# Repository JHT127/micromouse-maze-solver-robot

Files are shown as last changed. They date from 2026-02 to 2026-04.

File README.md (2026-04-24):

# 🐭 Micromouse Maze Solver Robot

> An autonomous maze-solving robot built from scratch — custom 3D-printed chassis, embedded C++ firmware, and classical control theory running on an ESP32.

**Team**:  Joud Thaher · Layan Salem · Labiba Sharia · Waad Ziadeh

**Instructor**: Dr. Wasel  

**University**: Birzeit University 

**Robot Name**: SHAMSHOON

---

## 🎯 What This Project Does

The robot navigates an 8×8 cell maze autonomously without any human input. It:

1. **Senses** walls in real time using three LIDAR sensors (front, left, right)
2. **Localises** itself in the maze using wheel encoders + gyroscope (StateSpace model)
3. **Plans** the shortest path to the center using the Flood Fill algorithm (BFS)
4. **Executes** precise movements using dual PID controllers — one per wheel
5. **Updates** its wall map as it explores and re-solves the path dynamically

Everything — from the PCB wiring to the 3D-printed body to the firmware — was designed and built by the team.

---

## 📸 Demo & Documentation

| Resource | Link |
|---|---|
| 📄 Full Project Presentation | [`docs/presentation.pdf`](docs/presentation.pdf) |
| 🗂️ Project Journey (Trello) | [Trello Board](https://trello.com/b/NDhEVEoG/micromouse-maze-solver-project) |
| 🏗️ Software Architecture | [`docs/ARCHITECTURE.md`](docs/ARCHITECTURE.md) |
| 🔧 Hardware Overview | [`hardware/README.md`](hardware/README.md) |
| 🖨️ 3D Print Files | [`hardware/3d-models/`](hardware/3d-models/) |

---

## 🤖 System Overview

```
┌─────────────────────────────────────────────────────────┐
│                    MazeNavigator                        │  ← Orchestration
├──────────────────────┬──────────────────────────────────┤
│     FloodFill        │       MotionController           │  ← Planning & Control
│  (BFS path solver)   │  (PID + StateSpace + gyro)      │
├──────────────────────┴──────────────────────────────────┤
│  LIDARSensor ×3  │  Encoder ×2  │  MPU6050Driver       │  ← Sensing
├──────────────────┴──────────────┴──────────────────────-┤
│              Motor ×2  │  PIDController ×2              │  ← Actuation
└─────────────────────────────────────────────────────────┘
                       ESP32 (Dual-core)
```

---

## 🛠️ Hardware Stack

| Component | Part | Role |
|---|---|---|
| **MCU** | ESP32 Dev Kit + Shield | Brain — dual-core processing, all GPIO |
| **Motors** | 2× N20 DC + L298N H-bridge | Differential drive |
| **Encoders** | 530 PPR wheel encoders | Odometry / speed feedback |
| **LIDAR** | 3× VL53L0X (I2C) | Wall detection: front, left, right |
| **IMU** | MPU6050 (6-axis) | Gyroscope for heading, accel for tilt |
| **Power** | Li-ion battery + Buck-Boost | Stable voltage across charge levels |
| **Chassis** | Custom 3D-printed PLA | Compact, lightweight, maze-optimised |

---

## 💻 Software Stack

| Layer | Module | What it does |
|---|---|---|
| **Sensing** | `LIDARSensor`, `MPU6050Driver`, `Encoder` | Read raw hardware data |
| **Control** | `PIDController`, `Motor` | Regulate wheel speed via PWM |
| **Localisation** | `StateSpace` | Kinematic model → tracks (x, y, θ) |
| **Motion** | `MotionController` | High-level: move forward, turn 90° |
| **Planning** | `FloodFill` | BFS flood → distance field for 8×8 maze |
| **Integration** | `MazeNavigator` | Ties everything into a solve loop |

**Toolchain**: C++ · Arduino Framework · PlatformIO · VS Code  
**Libraries**: `Adafruit MPU6050`, `Pololu VL53L0X`

---

## 🚀 Quick Start (Software)

### Prerequisites
- [VS Code](https://code.visualstudio.com/) + [PlatformIO extension](https://platformio.org/install/ide?install=vscode)
- ESP32 connected via USB

### Steps

```bash
git clone https://github.com/JHT127/micromouse-maze-solver-robot.git
cd micromouse-maze-solver-robot/software
```

Open in VS Code → PlatformIO will auto-install dependencies.

Edit `software/platformio.ini` to set your port:
```ini
upload_port = COM4       # Windows — change to your port
# upload_port = /dev/ttyUSB0   # Linux
# upload_port = /dev/cu.SLAB_USBtoUART  # macOS
```

```bash
# Build & upload firmware
platformio run -t upload

# Monitor serial output
platformio device monitor --baud 9600
```

> ⚠️ Keep the robot stationary during startup — the IMU calibrates for 500 samples.

---

## 📂 Repository Structure

```
micromouse-maze-solver-robot/
│
├── README.md                   ← You are here
│
├── docs/
│   ├── presentation.pdf        ← Full project presentation
│   ├── ARCHITECTURE.md         ← Deep-dive: algorithms & design decisions
│   └── component-READMEs/     ← Per-module documentation
│       ├── FloodFill.md
│       ├── PIDController.md
│       ├── StateSpace.md
│       └── ...
│
├── hardware/
│   ├── README.md               ← Hardware setup, wiring, BOM
│   └── 3d-models/             ← STL files for chassis 
│   
│
└── software/                   ← All firmware (PlatformIO project)
    ├── platformio.ini
    ├── src/
    │   └── main.cpp            ← Entry point
    ├── lib/                    ← 9 modular libraries
    │   ├── Motor/
    │   ├── Encoder/
    │   ├── PIDController/
    │   ├── StateSpace/
    │   ├── MPU6050Driver/
    │   ├── MotionController/
    │   ├── LIDARSensor/
    │   ├── FloodFill/
    │   └── MazeNavigator/
    ├── include/
    │   └── pins.h              ← All GPIO pin definitions
    ├── test/                   ← 12 unit + integration tests
    └── _archive_legacy_tests/  ← Early exploratory tests (historical)
```

---

## 🧪 Tests

12 tests cover every major component:

| Test | Type | What's validated |
|---|---|---|
| `FloodFill_test` | Unit | BFS algorithm, distance field, wall encoding |
| `PIDController_test` | Unit | Gain tuning, step response |
| `StateSpace_test` | Unit | Position prediction, coordinate transforms |
| `Encoders_Motors_test` | Unit | Speed measurement, PWM output |
| `LIDARSensor_test` | Unit | I2C addresses, ranging |
| `MPU6050_test` | Unit | Init, calibration, gyro drift |
| `MotionController_test` | Integration | Forward + turn commands |
| `turn_90_test` | Integration | Rotation accuracy |
| `MoveForward_WallDetection_test` | Integration | Movement + obstacle avoidance |
| `moveAndTurn_Test` | Integration | Sequential motion patterns |
| `CollisionAvoidance_test` | Integration | Emergency stop |
| `MazeNavigator_test` | Integration | Full maze solve loop |

See [`software/test/README.md`](software/test/README.md) for how to run individual tests.

---

## 🖨️ 3D Printing

The robot chassis was designed in-house and 3D-printed in PLA. Key design decisions:
- **Compact footprint** — fits within maze cell constraints
- **Lightweight** — reduces motor load, improves acceleration
- **Cardboard prototype first** — we validated dimensions before printing

STL files are in [`hardware/3d-models/`](hardware/3d-models/).  
*(If you're replicating this project, we recommend printing at 20% infill with 0.2mm layer height.)*

---

## 📐 Key Algorithms

### Flood Fill (Path Planning)
BFS from the goal (center 4 cells of the 8×8 grid) outward. Each cell stores a distance value and 4-bit wall encoding. The robot always moves to the lowest-distance neighbour — guaranteed shortest path.

### PID Control (Speed Regulation)
One PID per wheel. Input: target velocity. Feedback: encoder ticks. Output: PWM (0–255). Update rate: 50 Hz. Gains tuned manually: start with P, add I to remove steady-state error, add D to reduce oscillation.

### State Space (Localisation)
Kinematic differential-drive model tracking `[x, y, θ]`. Linear velocity from encoders, angular velocity from gyroscope. Heading convention: 0° = North, 90° = East, clockwise positive.

---

## 🔐 Security Note

This repository contains **no credentials, API keys, or Wi-Fi passwords**. The `platformio.ini` file contains a COM port reference (`COM4`) — update this to match your machine before uploading. No other machine-specific configuration is hardcoded.

---

## 📄 License

This project is submitted as academic coursework. You are welcome to study, fork, and learn from the code. Please note that we are students and still learning, so double-check everything. Do not forget to check out our journey documented on trello (the link is provided above if you click on the words Trello Board)!

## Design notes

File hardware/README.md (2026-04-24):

# 🔧 Hardware

This directory covers the physical robot — components, wiring, power, and mechanical design.

---

## Bill of Materials (BOM)

| # | Component | Qty | Purpose |
|---|---|-----|---|
| 1 | ESP32 Dev Kit (30-pin) + Shield | 1 | Main microcontroller — dual-core, 34 GPIO |
| 2 | L298N H-bridge Motor Driver | 1 | Drives both DC motors (handles high current) |
| 3 | N20 DC Motor (geared) | 2 | Differential drive locomotion |
| 4 | Wheel Encoder (530 PPR) | 2 | Odometry — measures exact wheel rotation |
| 5 | VL53L0X LIDAR (ToF sensor) | 3 | Wall detection: front, left, right |
| 6 | MPU-6050 IMU | 1 | 3-axis gyroscope + 3-axis accelerometer |
| 7 | Driven wheels | 2 | Forward/backward/turning motion |
| 8 | Caster wheel | 1 | Balance without extra motor |
| 9 | Lithium-ion battery | 1 | Main power source |
| 10 | Buck-Boost converter | 1 | Regulates voltage as battery drains |
| 11 | 3D-printed PLA chassis | 1 | Custom compact body |

---

## Wiring Summary

```
ESP32 GPIO          → Peripheral
─────────────────────────────────
GPIO 21 (SDA)       → All I2C devices (VL53L0X ×3, MPU6050)
GPIO 22 (SCL)       → All I2C devices
GPIO MOTOR_LEFT_A/B → L298N IN1/IN2
GPIO MOTOR_RIGHT_A/B→ L298N IN3/IN4
GPIO MOTOR_LEFT_PWM → L298N ENA (PWM)
GPIO MOTOR_RIGHT_PWM→ L298N ENB (PWM)
GPIO ENCODER_LEFT_A/B  → Left encoder A/B channels
GPIO ENCODER_RIGHT_A/B → Right encoder A/B channels
GPIO LIDAR_*_XSHOT  → VL53L0X XSHUT pins (for I2C address assignment)
GPIO LIDAR_*_INT    → VL53L0X interrupt pins
```

Full pin mapping: [`../software/include/pins.h`](../software/include/pins.h)

---

## I2C Address Assignment

The three VL53L0X sensors share the I2C bus but are assigned unique addresses at startup:

| Sensor | Address | XSHUT pin |
|---|---|---|
| Front LIDAR | `0x30` | `LIDAR_FRONT_XSHOT` |
| Left LIDAR | `0x31` | `LIDAR_LEFT_XSHOT` |
| Right LIDAR | `0x32` | `LIDAR_RIGHT_XSHOT` |

Sensors are enabled one at a time during boot — see `setup()` in `src/main.cpp`.

---

## Power Architecture

```
Li-ion Battery
      │
  Buck-Boost Converter (regulates output voltage)
      │
      ├──→ L298N (motor power, 7–12V line)
      └──→ ESP32 + Sensors (3.3V / 5V logic)
```

The buck-boost converter maintains stable voltage even as the battery discharges — critical for consistent PID and sensor performance.

---

## 3D Printed Chassis

See [`3d-models/`](3d-models/) for STL files.

**Design rationale:**
- Compact footprint to fit maze cells cleanly
- Lightweight PLA body reduces motor load → better acceleration
- Cardboard prototype was built first to validate dimensions before printing
- Component placement tested on cardboard before committing to print

**Recommended print settings:**
- Material: PLA
- Layer height: 0.2 mm
- Infill: 20%
- Supports: as needed for overhangs

---

## Component Notes

### ESP32 + Shield
The shield provides organized breakout connections and stable power rails. The dual-core processor lets us handle sensor reads and motor control simultaneously without blocking.

### L298N H-bridge
GPIO pins cannot supply enough current to drive motors directly. The L298N acts as a power bridge: it takes low-current direction signals from ESP32 GPIO and PWM signals for speed, and delivers the high-current output the motors need.

### VL53L0X LIDAR (×3)
Uses time-of-flight laser pulses — more reliable than ultrasonic in speed and precision. Three sensors give the robot full left/front/right wall awareness. Range: 50–1200 mm.

### MPU-6050
6-axis IMU. We use the gyroscope to confirm accurate 90° turns and correct wheel-slippage errors that encoders alone would miss. Works in combination with encoders for more reliable heading estimation.

### N20 Motors + Encoders
530 PPR encoders on motor shafts provide tick-level feedback. Used to calculate: exact distance travelled per tick, real-time wheel velocity (fed into PID), and odometry for the StateSpace position model.

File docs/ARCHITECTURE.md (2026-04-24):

# Architecture & Development Guide

This document explains the software architecture, design patterns, and how to extend the codebase.

## 🏗️ Architecture Overview

The micromouse software is organized into **9 independent layers**, each with clear responsibilities:

```
┌─────────────────────────────────────────┐
│  LAYER 9: MAZE NAVIGATOR                │  Application logic
│  Orchestrates all systems for maze-solving
└────────────────┬────────────────────────┘
                 │
┌─────────────────┴────────────────────────┐
│  LAYER 8: FLOOD FILL ALGORITHM            │  Path planning
│  BFS-based pathfinding on 8×8 grid        │
└─────────────────────────────────────────┘
                 │
┌─────────────────┴────────────────────────────────┐
│  LAYER 7: MOTION CONTROLLER                      │  Motion commands
│  High-level primitives: moveForward(), turnRight()
└────────────────┬────────────────┬────────────────┘
                 │                │
     ┌───────────┴────────────────┴────────────┐
     │                                         │
┌────┴──────────────────────┐   ┌─────────────┴──────────────┐
│ LAYER 6: CONTROL SYSTEMS   │   │ LAYER 6: PERCEPTION        │
│ ├─ PID Controllers        │   │ ├─ LIDAR Sensors (3x)      │
│ ├─ StateSpace Tracker     │   │ ├─ MPU6050 IMU             │
│ └─ Feedback Loops         │   │ └─ Sensor Fusion            │
└────┬──────────────────────┘   └─────────────┬──────────────┘
     │                                        │
     │  ┌────────────────────────────────────┘
     │  │
┌────┴──┴─────────────────────────────────────┐
│  LAYER 5: HARDWARE ABSTRACTION               │
│  ├─ Motor (PWM + direction)                 │
│  ├─ Encoder (GPIO + interrupt)              │
│  ├─ I2C Drivers (IMU, LIDAR)                │
│  └─ GPIO Pin Management                     │
└─────────────┬────────────────────────────────┘
              │
┌─────────────┴────────────────────────────────┐
│  LAYER 4: HARDWARE (Physical devices)        │
│  ├─ ESP32 Microcontroller                   │
│  ├─ L298N H-Bridge (motors)                 │
│  ├─ N20 DC Motors + Encoders                │
│  ├─ VL53L0X LIDAR (3x)                      │
│  └─ MPU6050 IMU                              │
└──────────────────────────────────────────────┘
```

## 🔧 Design Patterns Used

### 1. **Layered Architecture**
- Each layer depends only on layers below it
- Lower layers are generic and reusable
- Upper layers are robot-specific

**Example**: `MotionController` (Layer 7) uses `Motor` (Layer 5) but `Motor` knows nothing about motion.

### 2. **Hardware Abstraction**
- Hardware classes encapsulate device communication
- Application code never directly accesses GPIO/I2C
- Easy to swap implementations

**Example**: To use different motors, only modify `lib/Motor/Motor.cpp`, not application code.

### 3. **Composition Over Inheritance**
- `MazeNavigator` contains instances of other classes
- No deep inheritance hierarchies
- Easier to understand and modify

**Example**: `MazeNavigator` has a `MotionController*` pointer, not inheriting from it.

### 4. **Single Responsibility Principle**
- Each class does one thing well
- `Motor` only drives motors, doesn't track position
- `Encoder` only counts ticks, doesn't control motion

## 📚 Library Details

### Layer 5: Hardware Abstraction

#### `Motor.h` / `Motor.cpp`
```cpp
class Motor {
private:
    int pinA, pinB, pinPWM;  // H-bridge pins
public:
    void forward(int pwm);    // 0-255
    void backward(int pwm);   // 0-255
    void stop();
    void brake();
};
```
**Key Points**:
- Abstracts L298N H-bridge complexity
- PWM range: 0-255 (0% to 100%)
- No state tracking (stateless)

#### `Encoder.h` / `Encoder.cpp`
```cpp
class Encoder {
private:
    long tickCount;           // Interrupt-updated
    static Encoder* leftEncoderPtr;  // ISR access
public:
    long getTicks();
    float getDistance();      // In meters
    float getVelocity(float deltaTime);
};
```
**Key Points**:
- Uses hardware interrupts for accuracy
- No polling → always current
- Interrupt-driven (ISR called per encoder tick)

#### `LIDARSensor.h` / `LIDARSensor.cpp`
```cpp
class LIDARSensor {
private:
    int I2C_address;          // 0x30, 0x31, 0x32
public:
    void enable();            // Power on via GPIO
    void initialize(int address);
    uint16_t getRange();      // In mm
    void startContinuous();   // Continuous polling mode
};
```
**Key Points**:
- Multiple sensors, each with unique I2C address
- XSHUT pin for address control
- Range: 50-1200mm (0.05-1.2m)

#### `MPU6050Driver.h` / `MPU6050Driver.cpp`
```cpp
class MPU6050Driver {
private:
    float heading;
    float gyroBias;           // Calibration offset
public:
    bool initialize();        // Returns false if not found
    void calibrate(int samples);  // Zero gyro bias
    float getHeading();       // In degrees (0-360)
    void update();            // Call frequently
};
```
**Key Points**:
- Integrates gyro readings to heading angle
- Must calibrate (keep still 5 sec)
- Output: absolute heading (0=North, 90=East, etc.)

### Layer 6: Control Systems

#### `PIDController.h` / `PIDController.cpp`
```cpp
class PIDController {
private:
    float Kp, Ki, Kd;         // Tuning coefficients
    float integral, lastError;
public:
    PIDController(float kp, float ki, float kd);
    float calculate(float error, float deltaTime);
    void setOutputLimits(float min, float max);
};
```
**Key Points**:
- Generic PID for any process
- Output clamped to [-255, 255] for motor PWM
- For velocity: `error = targetVelocity - actualVelocity`

#### `StateSpace.h` / `StateSpace.cpp`
```cpp
class StateSpace {
private:
    float x, y, theta;        // Robot position
public:
    void update(float linVel, float angVel, float dt);
    float getX();
    float getY();
    float getTheta();         // In radians
};
```
**Key Points**:
- Integrates velocity into position
- Used to track robot location on maze grid
- Theta in radians (0 = East, π/2 = North, π = West, 3π/2 = South)

### Layer 7: Motion Control

#### `MotionController.h` / `MotionController.cpp`
```cpp
class MotionController {
private:
    Motor* leftMotor, *rightMotor;
    Encoder* leftEncoder, *rightEncoder;
    PIDController* leftPID, *rightPID;
    StateSpace* robot;
    // ... state for current motion ...
public:
    void moveForward(float distance);  // Non-blocking
    void turnRight(float angle);       // Non-blocking
    bool isMoving();                   // Check if done
    void update();                     // Call every 20ms
};
```
**Key Points**:
- Non-blocking: returns immediately
- Call `update()` in main loop to drive motion
- Coordinates PID + encoders + IMU

### Layer 8: Path Planning

#### `FloodFill.h` / `FloodFill.cpp`
```cpp
class FloodFill {
private:
    uint8_t walls[8][8];      // Bitfield: N=1, E=2, S=4, W=8
    uint16_t distances[8][8]; // BFS distance from goal
public:
    void updateWalls(Cell cell, bool front, bool right, bool left, Direction heading);
    Direction getNextMove(Cell current, Direction heading);
};
```
**Key Points**:
- Maze grid: 8×8 cells (Japanese Micromouse standard)
- BFS calculates shortest path from current position to goal
- Wall encoding: bitwise (each direction is one bit)

### Layer 9: System Integration

#### `MazeNavigator.h` / `MazeNavigator.cpp`
```cpp
class MazeNavigator {
private:
    MotionController* motion;
    LIDARSensor* frontLidar, *leftLidar, *rightLidar;
    FloodFill* maze;
public:
    void initialize(Cell start, Direction heading);
    void step();              // Call every 20ms in main loop
    bool isComplete();        // True when maze solved
};
```
**Key Points**:
- Orchestrates all subsystems
- Main loop: Sense → Plan → Act
- Two modes: exploration (learning map) and speed run (known map)

## 🔄 Data Flow Example: Moving Forward

```
main.cpp:setup()
  └─> navigator.initialize(Cell(0,0), NORTH)
  
main.cpp:loop() [every 20ms]
  └─> navigator.step()
       ├─> frontLidar.getRange()           [Sense]
       ├─> leftLidar.getRange()
       ├─> rightLidar.getRange()
       │
       ├─> floodFill.updateWalls(...)      [Plan]
       ├─> direction = floodFill.getNextMove(...)
       │
       ├─> motion.moveForward(distance)    [Act]
       │   ├─> leftMotor.forward(pwm)
       │   ├─> rightMotor.forward(pwm)
       │   └─> motion.update()
       │       ├─> leftEncoder.getVelocity()
       │       ├─> rightEncoder.getVelocity()
       │       ├─> leftPID.calculate(error)
       │       ├─> rightPID.calculate(error)
       │       ├─> imu.getHeading()
       │       └─> robot.update(velocity, heading)
       │
       └─> [Repeat next iteration]
```

## 🔨 How to Add a New Component

### Example: Adding a Compass Sensor

**Step 1: Create Hardware Abstraction** (`lib/CompassSensor/`)
```cpp
// CompassSensor.h
class CompassSensor {
private:
    int I2C_address;  // HMC5883L default: 0x1E
public:
    bool initialize();
    float getHeading();  // Returns 0-360 degrees
};

// CompassSensor.cpp
bool CompassSensor::initialize() {
    Wire.beginTransmission(I2C_address);
    // ... initialization code ...
}

float CompassSensor::getHeading() {
    // Read X, Y from sensor, calculate heading
}
```

**Step 2: Add to Higher Layers**
Update `StateSpace.cpp`:
```cpp
class StateSpace {
private:
    CompassSensor compass;  // Add this
public:
    void update(float linVel, CompassSensor& compass) {  // Add parameter
        // Use compass.getHeading() instead of gyro estimate
    }
};
```

**Step 3: Create Unit Test** (`test/CompassSensor_test.cpp`)
```cpp
#include "CompassSensor.h"

CompassSensor compass;

void setup() {
    Serial.begin(9600);
    compass.initialize();
}

void loop() {
    float heading = compass.getHeading();
    Serial.println(heading);
    delay(100);
}
```

**Step 4: Document** (add to `READMEs/CompassSensor.md`)

**Step 5: Update READMEs**
- Update `README.md` with new layer or component
- Update `test/README.md` with new test
- Update this file with new architecture

## 🎯 Code Style Guidelines

### Commenting Convention
All code uses this header format:
```cpp
//------------------------------------------------------------
// SECTION HEADER
// Purpose: Explanation of why this exists
//------------------------------------------------------------
```

### Variable Naming
- Member variables: camelCase (`motorSpeed`, `encoderCount`)
- Constants: UPPER_CASE (`MOTORS_PER_TICK`, `MAZE_SIZE`)
- Functions: camelCase (`initialize()`, `getDistance()`)

### Class Organization
```cpp
class MyClass {
private:
    // Declare member variables
    // Define helper functions
    
public:
    // Declare public interface
    // Getters first
    // Setters second
    // Action methods third
};
```

### Comments
- **Why** comments above complex code
- **What** comments only if code is unclear
- Avoid obvious comments
```cpp
// Good
if (range < WALL_DISTANCE) {
    // Stop immediately - collision imminent
    motor.stop();
}

// Bad
int x = 5; // Set x to 5
```

## 🧪 Testing Strategy

### Unit Test Pattern
```cpp
// Test only ONE component
// Setup: Create instance, initialize
// Execute: Call methods
// Verify: Check Serial output
// Halt: while(1) delay(1000);
```

### Integration Test Pattern
```cpp
// Test MULTIPLE components working together
// Setup: Initialize all components
// Execute: Run realistic scenario
// Verify: Check combined behavior
// Halt: when complete
```

## 🚀 Performance Considerations

### Critical Timing
- **Main loop**: Must run at 50Hz (20ms)
- **Encoder ISR**: Must complete <100µs
- **Motor PWM**: 20kHz (ESP32 default)

### Memory Usage
- **Stack**: ~4KB used (ESP32 has 2KB SRAM per stack)
- **Heap**: ~50KB available for objects
- **Flash**: ~500KB used for code

## 🔍 Debugging Tips

### Use Serial Monitor
```cpp
Serial.print("Motor PWM: ");
Serial.println(pwmValue);
delay(100);  // Don't flood Serial!
```

### Common Issues
1. **Motors not responding**: Check motor power supply, GPIO pins
2. **Encoder counts wrong**: Verify PPR constant, check GPIO interrupts
3. **LIDAR I2C failing**: Check pull-up resistors, address selection
4. **IMU calibration fails**: Ensure board is level and motionless

## 📚 Further Reading

- `READMEs/` directory - Component-specific details
- `test/` directory - Working code examples
- `src/main.cpp` - Real application code
- Individual `.h` files - API documentation

---

**Last Updated**: April 24, 2026
**Status**: Complete Architecture Documentation

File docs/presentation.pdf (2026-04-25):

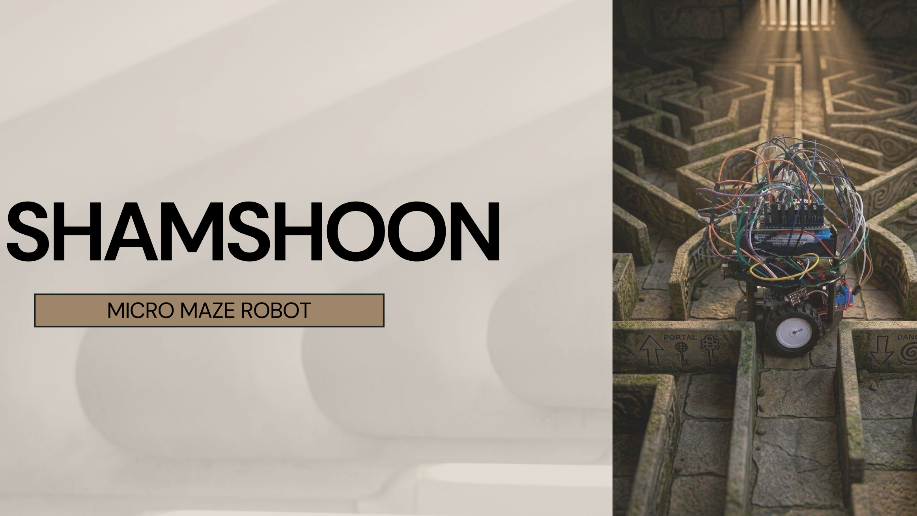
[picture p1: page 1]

# SHAMSHOON

MICRO MAZE ROBOT

# Our team

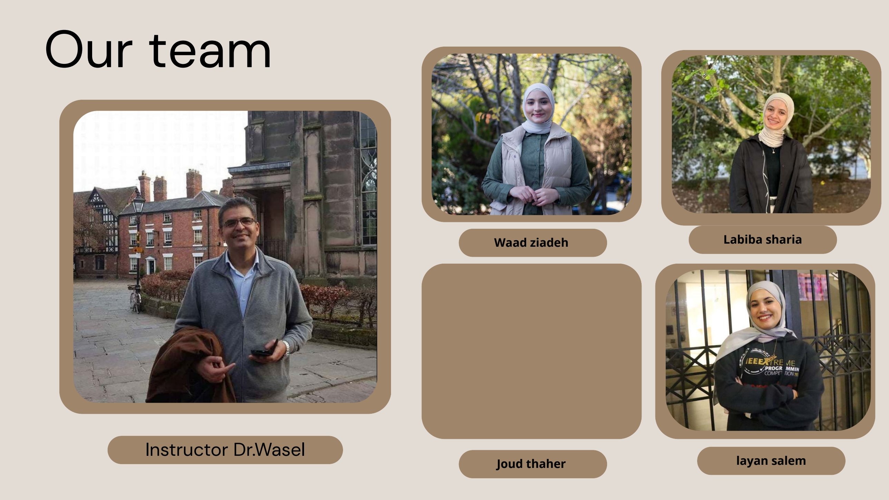
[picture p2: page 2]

Instructor Dr.Wasel

Waad ziadeh | Labiba sharia

Joud thaher

layan salem

# Component Overview & Purpose

### 7 Components

3

### 2 Motors

Sensors

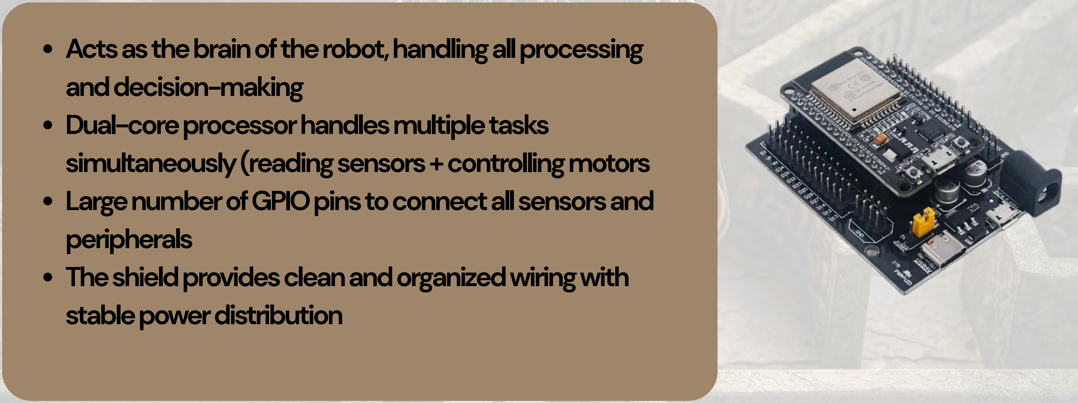
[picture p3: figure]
and decision-making Dual-core processor handles multiple tasks; peripherals; stable power distribution

Acts as the brain of the robot, handling all processing

simultaneously (reading sensors + controlling motors Large number of GPIO pins to connect all sensors and

The shield provides clean and organized wiring with

### 1 ESP32 + Shield Microcontroller

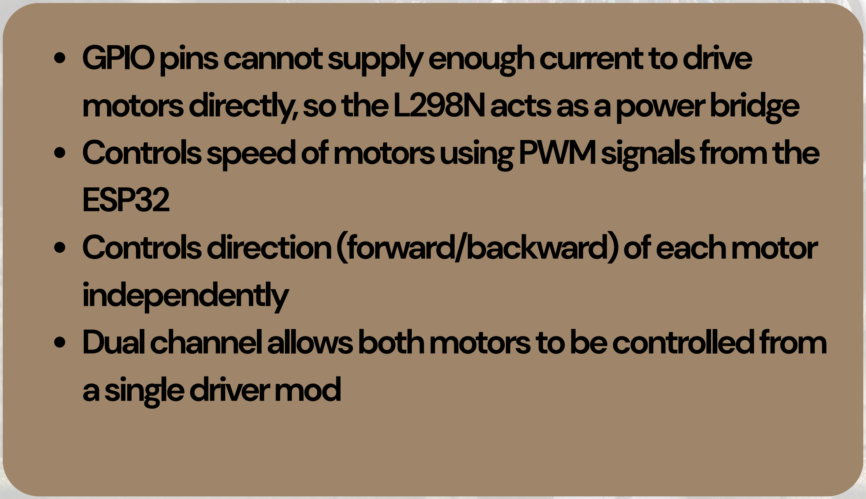
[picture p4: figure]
ESP32; independently; a single driver mod

GPIO pins cannot supply enough current to drive motors directly, so the L298N acts as a power bridge Controls speed of motors using PWM signals from the

Controls direction (forward/backward) of each motor

Dual channel allows both motors to be controlled from

### 2 L298N Motor Driver (H bridge)

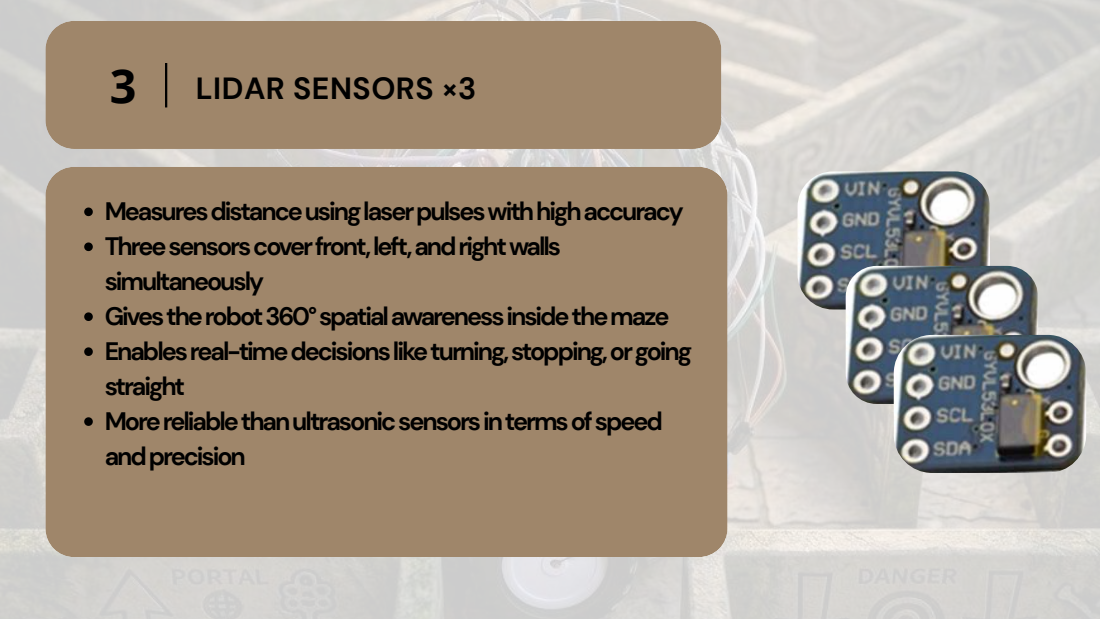
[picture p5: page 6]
3 LIDAR SENSORS ×3

Measures distance using laser pulses with high accuracy
Three sensors cover front, left, and right walls
simultaneously
Gives the robot 360° spatial awareness inside the maze
Enables real-time decisions like turning, stopping, or going
straight
More reliable than ultrasonic sensors in terms of speed
and precision

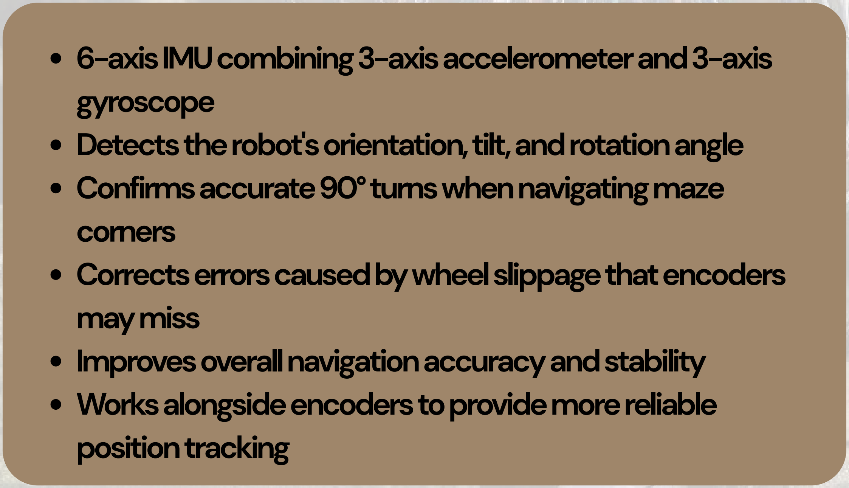
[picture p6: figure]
gyroscope; corners; may miss; position tracking
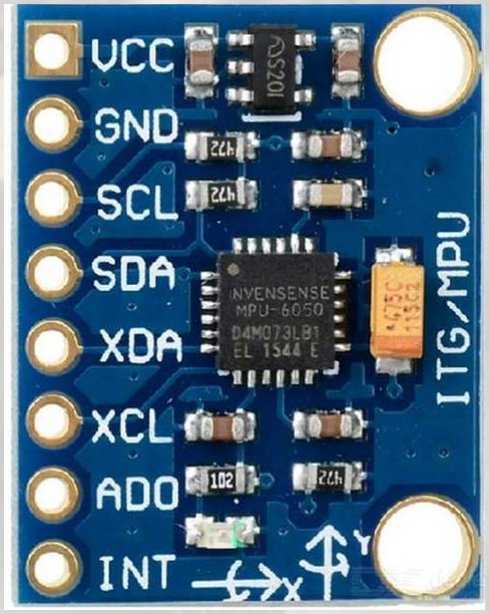
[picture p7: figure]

6-axis IMU combining 3-axis accelerometer and 3-axis

Detects the robot's orientation, tilt, and rotation angle Confirms accurate 90° turns when navigating maze

Corrects errors caused by wheel slippage that encoders

Improves overall navigation accuracy and stability Works alongside encoders to provide more reliable

### 4 MPU-6050 (Accelerometer + Gyroscope)

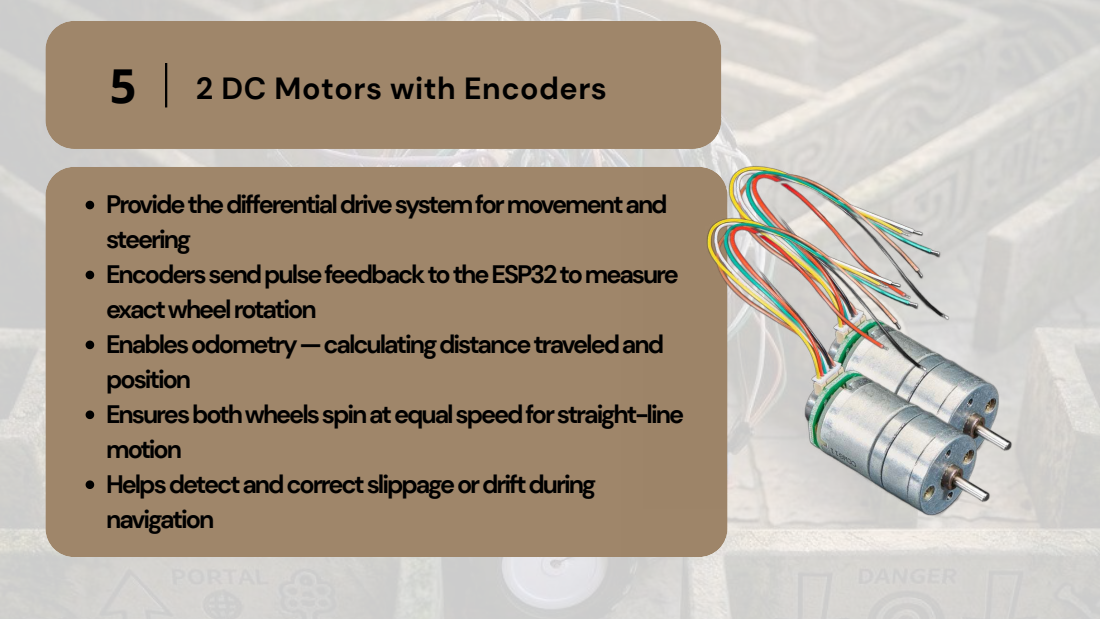
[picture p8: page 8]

5 2 DC Motors with Encoders

Provide the differential drive system for movement and
steering
Encoders send pulse feedback to the ESP32 to measure
exact wheel rotation
Enables odometry — calculating distance traveled and
position
Ensures both wheels spin at equal speed for straight-line
motion
Helps detect and correct slippage or drift during
navigation

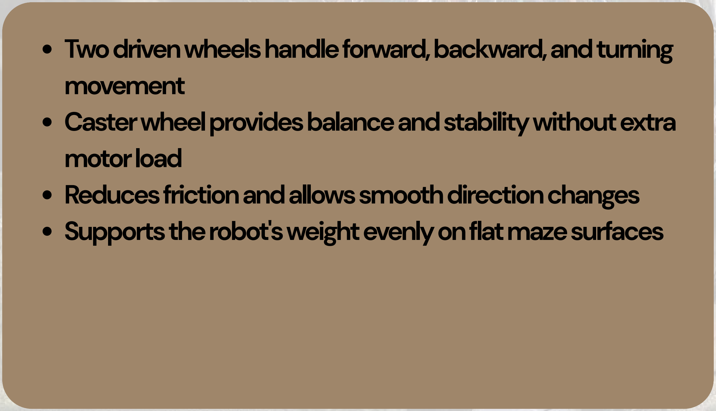
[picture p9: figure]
movement; motor load
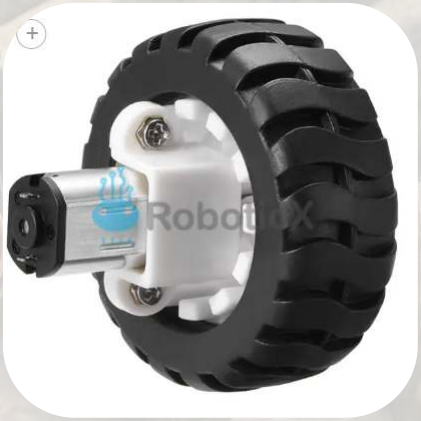
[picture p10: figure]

Two driven wheels handle forward, backward, and turning

Caster wheel provides balance and stability without extra

Reduces friction and allows smooth direction changes Supports the robot's weight evenly on flat maze surfaces

### 6 Wheels + Caster Wheel

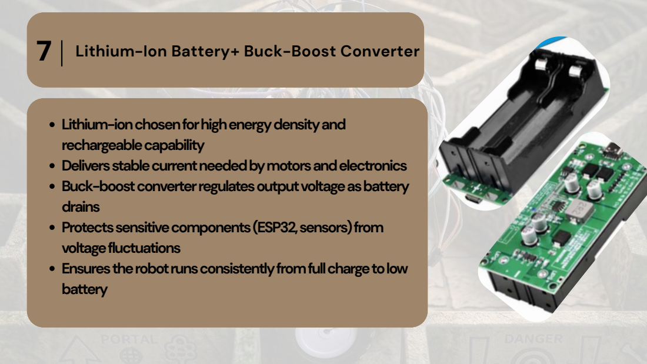
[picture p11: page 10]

7 Lithium-Ion Battery+ Buck-Boost Converter

Lithium-ion chosen for high energy density and
rechargeable capability
Delivers stable current needed by motors and electronics
Buck-boost converter regulates output voltage as battery
drains
Protects sensitive components (ESP32, sensors) from
voltage fluctuations
Ensures the robot runs consistently from full charge to low
battery

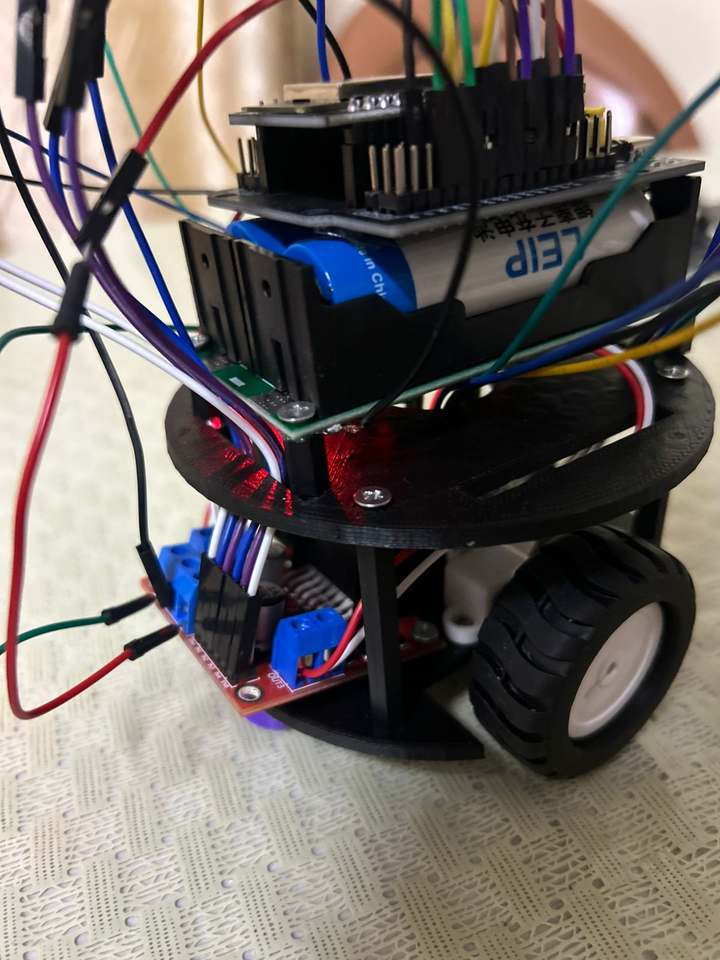
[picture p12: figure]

# Robot Design

We designed the robot body using 3D printing to be compact and lightweight in order to improve its overall performance.

To allow smooth
movement inside
the maze

## Design Decision: Small and Lightweight Structure

To allow smooth
movement
inside the mazTo
improve
maneuverability
in narrow pathse

Less mass →
higher speed

Reduced load on
the motors

A lighter robot requires less torque, which increases acceleration and improves response time.

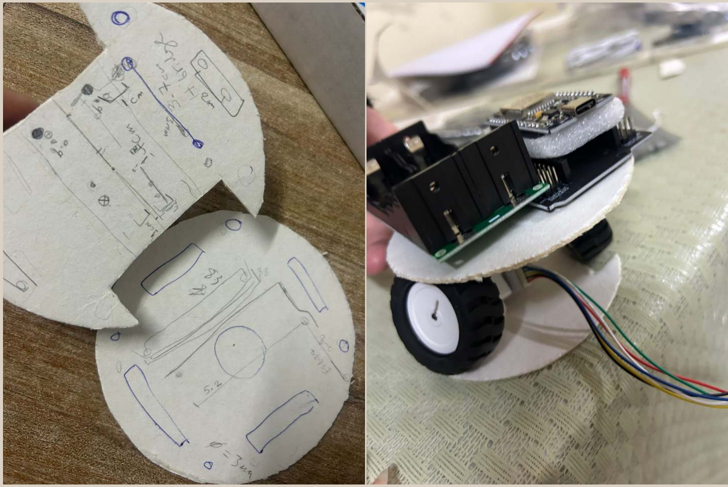
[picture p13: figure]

Before printing the final body, we first created a cardboard
prototype to take accurate measurements and test
component placement.
This step helped us determine the correct dimensions and avoid material waste before 3D printing.

## Robot Body Design and Development

High precision
manufacturig

## Design Choice: 3D Printing Technology

Ability to
customize the
design

Modern
manufacturing
approach

Lightweight
structure

We used 3D printing to gain practical experience with advanced manufacturing technology, which is considered an important tool in the future of engineering and product development. As Dr. Wasel mentioned, 3D printing represents a key part of future innovation and rapid prototyping.

## Design Choice: 3D Printing Technology

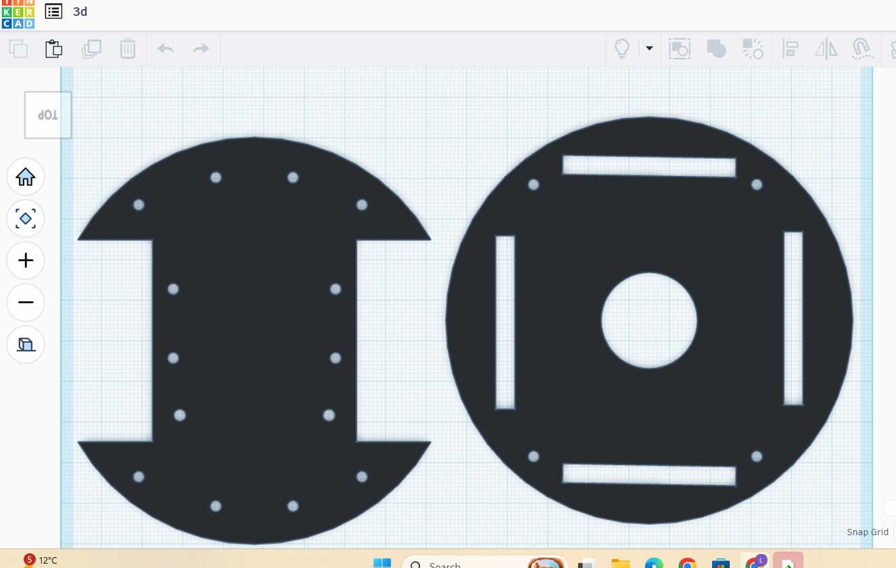
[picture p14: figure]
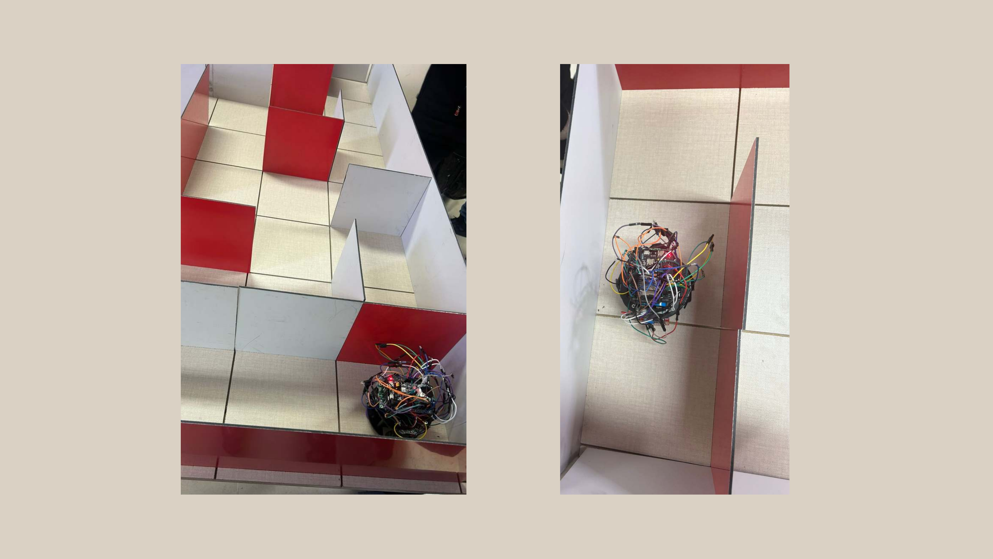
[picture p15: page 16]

# State Space Modelling

Track robot position ([x, y, θ])

Provide position estimation for maze navigation

Predict motion from control inputs

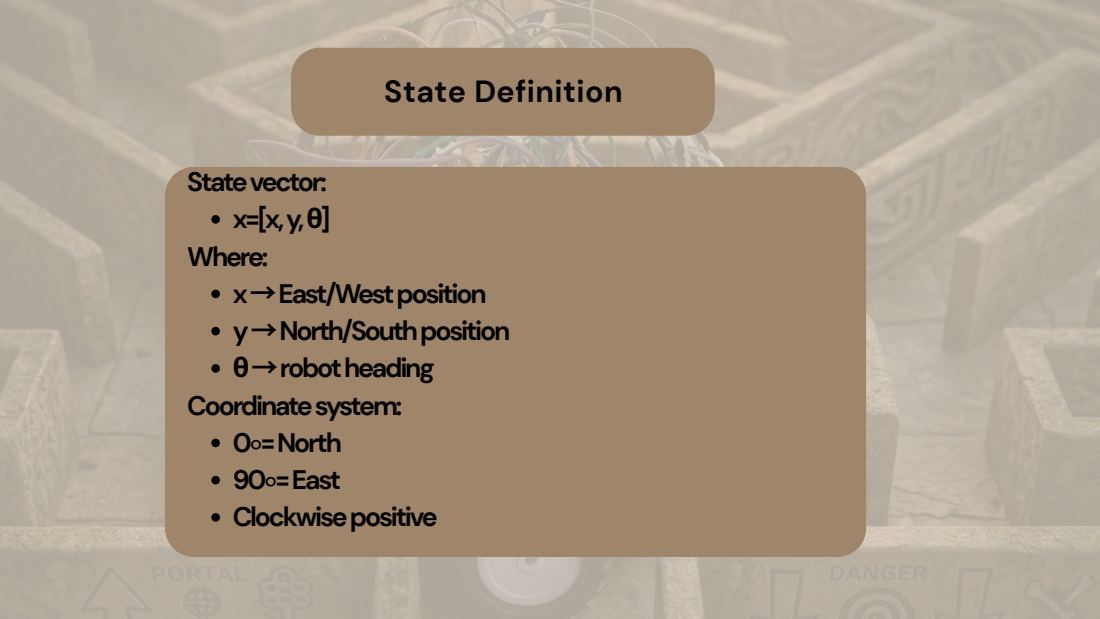
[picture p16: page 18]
State Definition

State vector:
Where:
x → East/West position
y → North/South position
θ→ robot heading
Coordinate system:
0∘= North
90∘= East
Clockwise positive

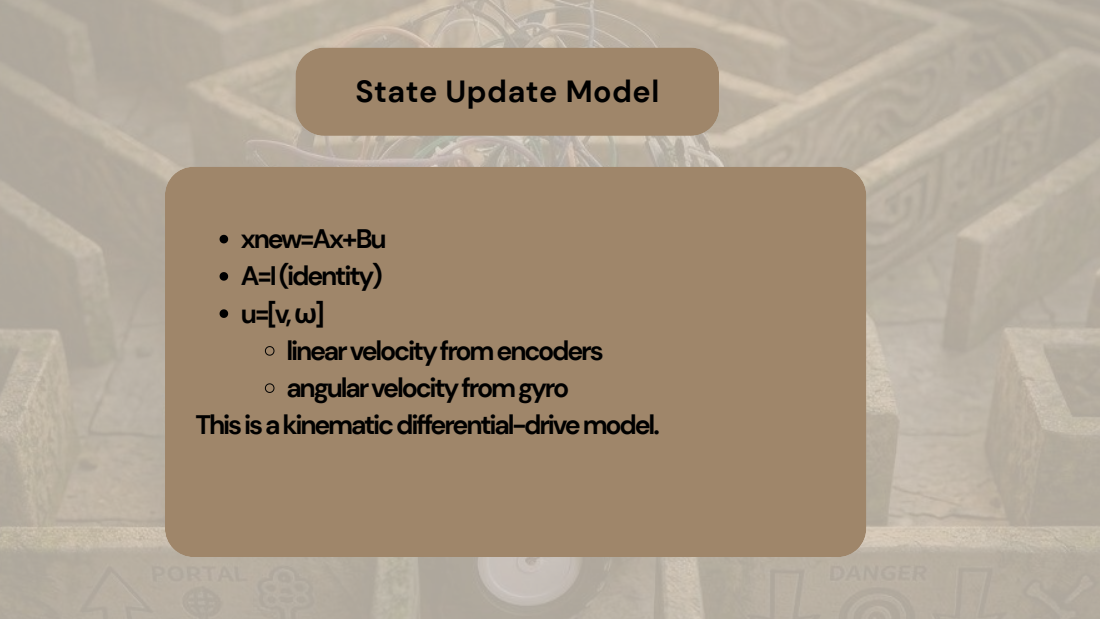
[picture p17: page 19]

State Update Model

xnew =Ax+Bu
A=I (identity)
linear velocity from encoders
angular velocity from gyro
This is a kinematic differential-drive model.

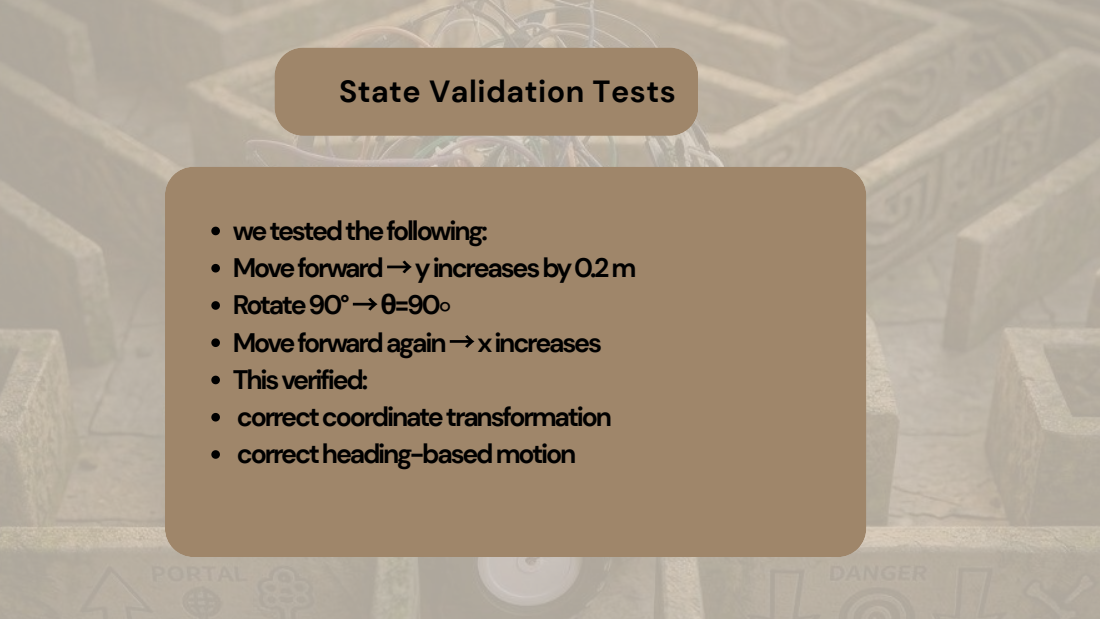
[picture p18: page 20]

State Validation Tests

we tested the following:
Move forward → y increases by 0.2 m
Rotate 90° →θ=90∘
Move forward again → x increases
This verified:
correct coordinate transformation
correct heading-based motion

PID Control | Maintain constant speed

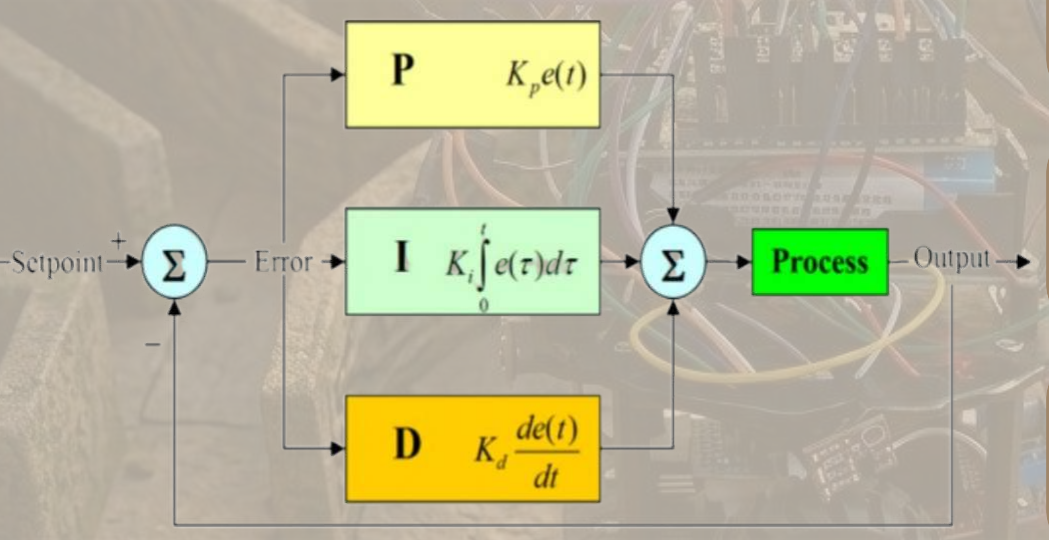
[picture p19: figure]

Prevent drift and oscillation

Achieve accurate 90° turns

Adjusts motor power to minimize error between: Target speed and Measured speed

Error:
e = target speed − measured speed (from encoders)

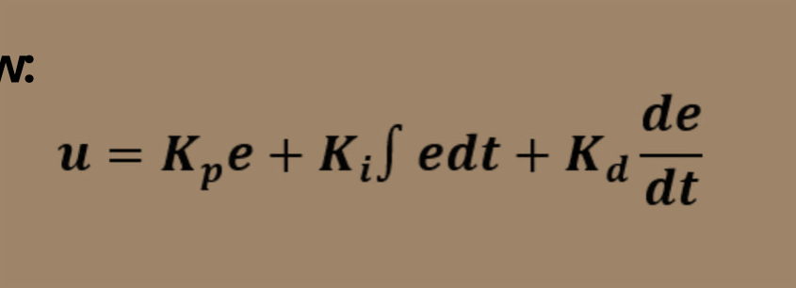
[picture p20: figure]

Control law:

Proportional–Integral–Derivative controller

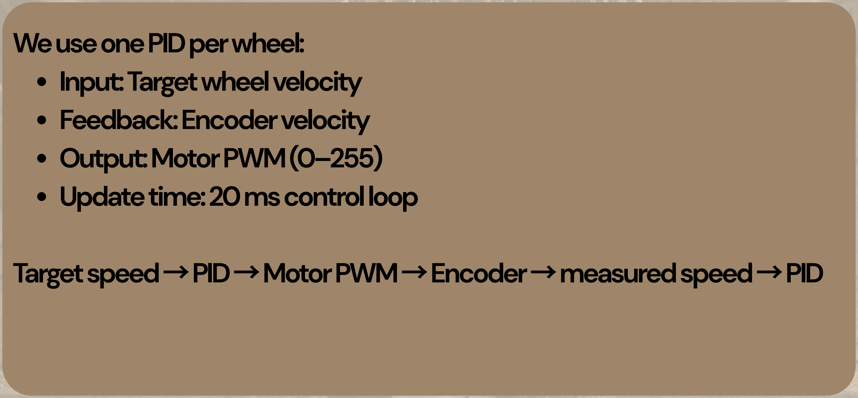
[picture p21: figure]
We use one PID per wheel: Input: Target wheel velocity Feedback: Encoder velocity Output: Motor PWM (0–255) Update time: 20 ms control loop

Target speed → PID → Motor PWM → Encoder → measured speed → PID

Control Loop Flow

Motion Primitives Using PID

1.Start with P only
2.Add I to remove steady-state error 3.Add D to reduce oscillation
Final gains chosen experimentally.

Manual PID Tuning

# FloodFill Algorithm

8×8 grid (64 cells) maze

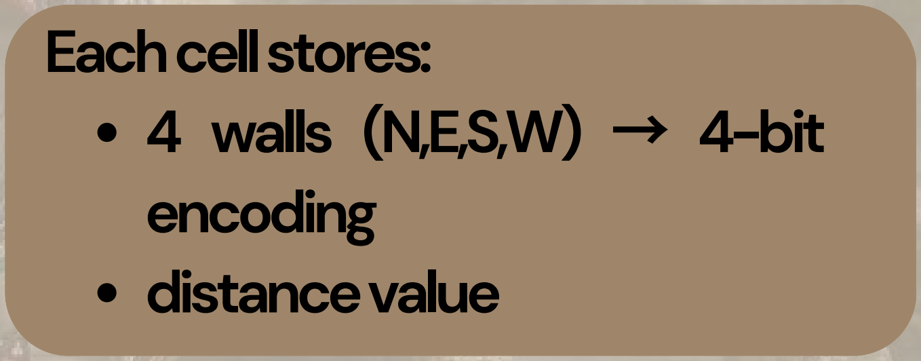
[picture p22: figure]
Each cell stores: 4 walls (N,E,S,W) → 4-bit encoding distance value

Goal: center 4 cells

Steps:
1.Initialize goal distance = 0
2.Set others = ∞
3.BFS flood from goal
4.Each cell gets minimum distance Robot always moves to lowest neighbor.

Algorithm

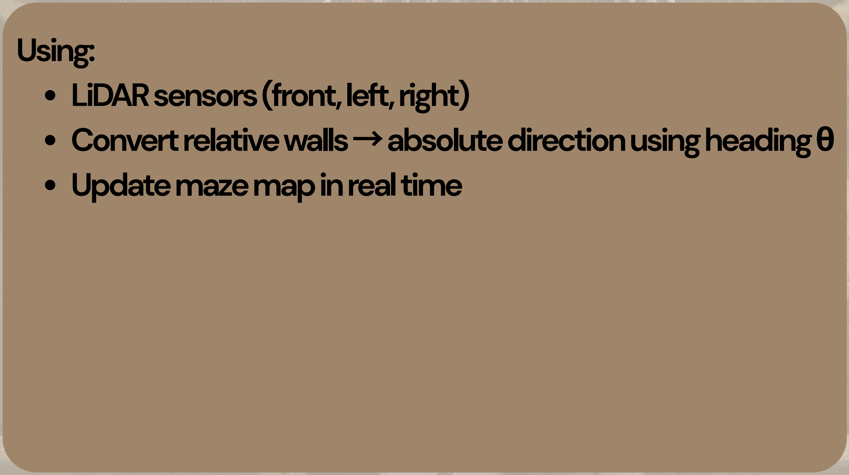
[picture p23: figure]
Using: LiDAR sensors (front, left, right); Update maze map in real time

Convert relative walls → absolute direction using heading θ

Wall Detection

Path Decision

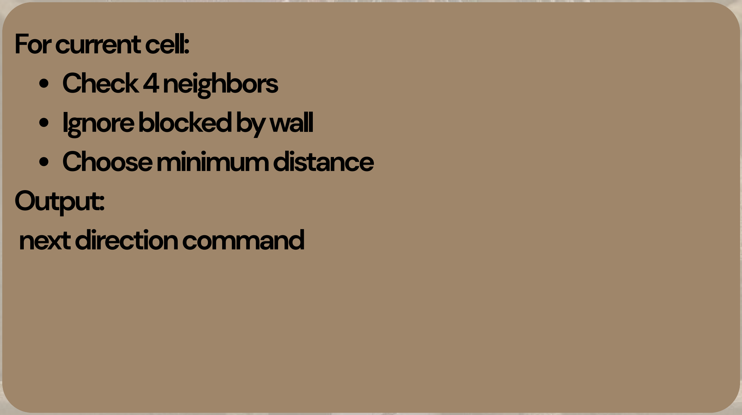
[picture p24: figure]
For current cell: Check 4 neighbors Ignore blocked by wall Choose minimum distance Output: next direction command

FloodFill → next cell →
MotionController → PID speed control → Motors → Encoders + MPU → StateSpace → updated position → repeat

Full System Flow

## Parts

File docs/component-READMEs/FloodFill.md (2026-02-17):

# FloodFill Maze Algorithm (Day 7a)

## What is this?

The brain of the maze solver. Implements the Flood Fill algorithm to:
1. Learn the maze layout by detecting walls
2. Calculate the shortest path to the goal
3. Decide which direction the robot should move next

Imagine filling the maze from the goal with water - it spreads to all reachable cells. Cells closer to the goal have lower "water level". Robot always moves to the cell with the lowest level.

## How It Works

### Representation
- **8×8 grid** of cells (64 total)
- Each cell can have walls on 4 sides (N, E, S, W)
- **Goal**: Center 4 cells at (3,3), (3,4), (4,3), (4,4)
- **Wall encoding**: 4-bit number (N=1, E=2, S=4, W=8)

### Algorithm Stages

**Stage 1: Initialize**
```
- Set all boundary walls (maze edges)
- Set goal cells to distance 0
- All other cells to infinity
```

**Stage 2: Detect Walls**
```
- Read LIDAR sensors
- Convert front/left/right to absolute directions
- Add walls to maze map
```

**Stage 3: Calculate Distances**
```
- BFS flood fill from goals
- Each iteration, cells update from neighbors
- Repeat until all cells have minimum distance
```

**Stage 4: Get Next Move**
```
- Look at all 4 neighbors
- Skip if wall blocks the way
- Choose neighbor with lowest distance
- Return that direction
```

## How to Use

```cpp
#include "FloodFill.h"

FloodFill maze;

void setup() {
    Serial.begin(115200);
    maze.initialize();
}

void loop() {
    // Current robot position
    Cell currentPos(x, y);
    Direction heading = NORTH;
    
    // Update walls based on sensors
    bool frontWall = true;   // From LIDAR
    bool rightWall = false;
    bool leftWall = false;
    
    maze.updateWalls(currentPos, frontWall, rightWall, leftWall, heading);
    
    // Get next move direction
    Direction nextMove = maze.getNextMove(currentPos, heading);
    
    // Check if at goal
    if (maze.isAtGoal(currentPos)) {
        Serial.println("Goal reached!");
    }
}
```

## Key Structures

### Cell
```cpp
struct Cell {
    int x;  // 0-7 (horizontal)
    int y;  // 0-7 (vertical)
};
```

### Direction Enum
```cpp
enum Direction {
    NORTH = 0,  // +Y direction (up)
    EAST = 1,   // +X direction (right)
    SOUTH = 2,  // -Y direction (down)
    WEST = 3    // -X direction (left)
};
```

### Wall Bitfield
```cpp
walls[x][y] format:
- Bit 0 (=1):   North wall
- Bit 1 (=2):   East wall
- Bit 2 (=4):   South wall
- Bit 3 (=8):   West wall

Example: walls[3][3] = 0x05 means:
- 0x05 = binary 0101
- North wall (bit 0) = 1 ✓
- East wall (bit 1) = 0 ✗
- South wall (bit 2) = 1 ✓
- West wall (bit 3) = 0 ✗
```

## Functions

**Setup:**
- `initialize()` - Set boundary walls, initialize maze
- `reset()` - Clear visited flag but keep walls

**Wall Management:**
- `setWall(cell, direction, exists)` - Add/remove wall
- `updateWalls(cell, front, right, left, heading)` - Update from sensors

**Pathfinding:**
- `getNextMove(current, heading)` - Get best direction
- `isAtGoal(cell)` - Check if reached center
- `calculateDistances()` - Recalculate distance field

**Utility:**
- `relativeToAbsolute(relative, heading)` - Convert directions
- `getTurnAngle(from, to)` - Calculate turn needed

## Maze Layout

```
     0   1   2   3   4   5   6   7
   +---+---+---+---+---+---+---+---+
 7 |   |   |   |   |   |   |   |   |
   +---+---+---+---+---+---+---+---+
 6 |   |   |   |   |   |   |   |   |
   +---+---+---+---+---+---+---+---+
 5 |   |   |   |   |   |   |   |   |
   +---+---+---+---+---+---+---+---+
 4 |   |   |   | G | G |   |   |   |
   +---+---+---+---+---+---+---+---+
 3 |   |   |   | G | G |   |   |   |
   +---+---+---+---+---+---+---+---+
 2 |   |   |   |   |   |   |   |   |
   +---+---+---+---+---+---+---+---+
 1 |   |   |   |   |   |   |   |   |
   +---+---+---+---+---+---+---+---+
 0 | S |   |   |   |   |   |   |   |
   +---+---+---+---+---+---+---+---+
```

- S = Start (0,0)
- G = Goal (3,3), (3,4), (4,3), (4,4)

## Example: Distance Field

After reaching the goal, the maze looks like:

```
     0   1   2   3   4   5   6   7
   +---+---+---+---+---+---+---+---+
 7 | 8 | 7 | 6 | 7 | 8 | 9 |10 |11 |
   +---+---+---+---+---+---+---+---+
 6 | 7 | 6 | 5 | 6 | 7 | 8 | 9 |10 |
   +---+---+---+---+---+---+---+---+
 5 | 6 | 5 | 4 | 5 | 6 | 7 | 8 | 9 |
   +---+---+---+---+---+---+---+---+
 4 | 5 | 4 | 3 | 1 | 0 | 1 | 2 | 3 |
   +---+---+---+---+---+---+---+---+
 3 | 4 | 3 | 2 | 0 | 1 | 2 | 3 | 4 |
   +---+---+---+---+---+---+---+---+
 2 | 3 | 2 | 1 | 1 | 2 | 3 | 4 | 5 |
   +---+---+---+---+---+---+---+---+
 1 | 2 | 1 | 2 | 3 | 4 | 5 | 6 | 7 |
   +---+---+---+---+---+---+---+---+
 0 | 1 | 0 | 1 | 2 | 3 | 4 | 5 | 6 |
   +---+---+---+---+---+---+---+---+
```

Numbers show distance to goal (lower = closer).

## Wall Detection Directions

When robot reports walls as front/right/left, they're relative to current heading.

**Conversion:**
```cpp
Heading = NORTH (0)
- Front → NORTH
- Right → EAST
- Left → WEST

Heading = EAST (1)
- Front → EAST
- Right → SOUTH
- Left → NORTH
```

## Testing

Test with `FloodFill_test.cpp`:
- Initialize maze
- Add walls manually
- Verify distance calculation
- Test getNextMove() function
- Check at-goal detection

## Algorithm Complexity

- **Time**: O(N) per update (N = grid size = 64)
- **Space**: O(N) for distance array
- **Iterations**: ~20-30 for full maze exploration

## Common Issues

| Problem | Solution |
|---|---|
| Robot goes in circles | Check wall detection and updateWalls() logic |
| Always moves same direction | Verify getNextMove() is being called |
| Robot stops at walls | Check isAtGoal() implementation |
| Walls not added | Verify sensor readings are correct |

## Integration with Other Components

```
MazeNavigator calls:
├─ updateWalls() with LIDAR readings
├─ getNextMove() for direction
└─ isAtGoal() for completion check
```

## Next Steps

After FloodFill works:
1. Combine with MotionController for movement
2. Create MazeNavigator for full exploration
3. Add speed run mode with known map

## References

- Flood Fill algorithm commonly used in maze solving contests
- Typical competition robot uses this or recursive backtracking
- Goal: Reach center in minimal moves (exploration)
- Speed run: Follow optimal path as fast as possible

---

**Why this file exists:**
- Algorithm explanation for reference
- Cell structure and wall encoding
- Integration guide for MazeNavigator

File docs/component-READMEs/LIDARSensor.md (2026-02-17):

# LIDAR Distance Sensor (Day 6)

## What is this?

Reads three VL53L0X Time-of-Flight (ToF) distance sensors to detect walls around the robot. Each sensor measures distance and reports if a wall is present.

**3 Sensors:**
- Front LIDAR → detects walls ahead
- Left LIDAR → detects walls to the left
- Right LIDAR → detects walls to the right

## Hardware Connections

**Each VL53L0X has:**
- VCC → 3.3V
- GND → GND
- SDA → ESP32 pin 21 (shared I2C)
- SCL → ESP32 pin 22 (shared I2C)
- XSHUT → Control pin (GPIO)

**XSHUT Pins:**
- Front LIDAR → pin 16
- Left LIDAR → pin 18
- Right LIDAR → pin 23

**Important Notes:**
1. Add 10kΩ pullup resistors on SDA/SCL
2. All sensors share I2C bus but have different addresses (0x30, 0x31, 0x32)
3. XSHUT pins allow turning sensors on/off individually

## How to Use

```cpp
#include "LIDARSensor.h"

// Create sensor objects
LIDARSensor frontLidar(16, 17);   // XSHUT, INT pins
LIDARSensor leftLidar(18, 19);
LIDARSensor rightLidar(23, 5);

void setup() {
    Serial.begin(115200);
    
    // IMPORTANT: Disable all sensors first
    frontLidar.disable();
    leftLidar.disable();
    rightLidar.disable();
    delay(50);
    
    // Enable and address one at a time
    frontLidar.enable();
    delay(50);
    frontLidar.initialize(0x30);
    
    leftLidar.enable();
    delay(50);
    leftLidar.initialize(0x31);
    
    rightLidar.enable();
    delay(50);
    rightLidar.initialize(0x32);
}

void loop() {
    // Read distances
    int frontDist = frontLidar.getDistanceMM();
    int leftDist = leftLidar.getDistanceMM();
    int rightDist = rightLidar.getDistanceMM();
    
    Serial.print("Front: ");
    Serial.print(frontDist);
    Serial.print("mm  Left: ");
    Serial.print(leftDist);
    Serial.print("mm  Right: ");
    Serial.print(rightDist);
    Serial.println("mm");
    
    // Check for walls
    if (frontLidar.isWallDetected()) {
        Serial.println("Wall ahead!");
    }
    
    delay(100);
}
```

## Functions

**Setup:**
- `initialize(newAddress)` - Assign unique I2C address (0x30/0x31/0x32)
- `enable()` - Set XSHUT high to power on
- `disable()` - Set XSHUT low to power off

**Reading:**
- `getDistanceMM()` - Distance in millimeters
- `getDistanceMeters()` - Distance in meters (mm / 1000)
- `isWallDetected()` - Returns true if distance < 150mm

**Status:**
- `isReady()` - Check if initialized

## Key Parameters

```
Sensor Type:        VL53L0X (Time-of-Flight)
Default Address:    0x29 (all sensors start here!)
Final Addresses:    0x30 (front), 0x31 (left), 0x32 (right)
Distance Range:     5cm to 2m
Wall Threshold:     15cm (0.15m = 150mm)
I2C Bus:            Shared with MPU6050
Polling Speed:      ~10 measurements per second
```

## Critical: Sequential Initialization

**All VL53L0X sensors start at address 0x29, causing an I2C conflict!**

**Solution**: Initialize one at a time using XSHUT pins:

```cpp
// Step 1: Disable all
frontLidar.disable();  // Pull XSHUT low
leftLidar.disable();
rightLidar.disable();
delay(50);  // Wait for power-down

// Step 2: Enable and address sequentially
frontLidar.enable();      // Pull XSHUT high for front
delay(50);
frontLidar.initialize(0x30);  // Now it's at 0x30
// Front is now safe, other two still off

leftLidar.enable();
delay(50);
leftLidar.initialize(0x31);
// Left is now at 0x31

rightLidar.enable();
delay(50);
rightLidar.initialize(0x32);
// All three at unique addresses - no conflict!
```

## Wall Detection Threshold

Default threshold is 15cm (150mm):

```cpp
// Walls closer than 15cm are detected
bool wall = frontLidar.isWallDetected();

// To change threshold, modify in header:
static constexpr float WALL_THRESHOLD = 0.15;  // 15cm
```

## Distance Readings

```
Distance < 50mm:   Sensor error / out of range
50mm - 150mm:      Wall detected
150mm - 1000mm:    Open space
> 1000mm (1m):     No wall (far away)
```

## Coordinate Directions

```
     FRONT
      |
LEFT--+--RIGHT
      |
    BACK
```

Sensor placement on robot:
- Front points forward (direction of travel)
- Left points to the left
- Right points to the right

## I2C Bus Sharing

Both MPU6050 and LIDARs share I2C bus:

```
I2C Bus (pins 21, 22)
    ├─ MPU6050      @ 0x68
    ├─ Front LIDAR  @ 0x30
    ├─ Left LIDAR   @ 0x31
    └─ Right LIDAR  @ 0x32
```

No conflicts as long as addresses are unique.

## Testing

Test with `LIDARSensor_test.cpp`:
- Initialize each sensor individually
- Verify distance readings in open space
- Place hand in front of each sensor
- Verify wall detection threshold
- Check measurements are stable

## Common Issues

| Problem | Solution |
|---|---|
| "Sensor not found at 0x29" | Check I2C wiring, verify pullup resistors |
| Wrong I2C address | Run sequential init (disable all first) |
| Inconsistent readings | Check XSHUT pin connections |
| High distance values | Sensor pointing at reflective surface |
| Low distance values | Sensor pointing at dark/non-reflective surface |

## Measurement Accuracy

```
Close range (5-20cm):    ±5cm error
Mid range (20-100cm):    ±3cm error
Far range (100cm+):      ±10% error
```

For a 20cm maze cell, expect ±2-3cm measurement uncertainty.

## Power Consumption

- Off (XSHUT low):    < 1µA
- Idle (XSHUT high):  < 5mA
- Measuring:          ~15mA each
- All three running:  ~45mA total

## Triggering Measurements

Each call to `getDistanceMM()`:
1. Triggers a measurement
2. Waits for completion (~30ms typical)
3. Reads result
4. Returns distance

This is why LIDAR calls should not be in tight loops.

## Next Steps

After LIDAR works:
1. Use readings to detect maze walls
2. Feed wall data to FloodFill algorithm
3. Autonomous maze exploration

---

**Why this file exists:**
- I2C addressing strategy explanation
- Sequential initialization guide
- Integration reference for maze solver

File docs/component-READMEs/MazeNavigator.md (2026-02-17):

# Maze Navigator - Full System Integration (Day 7b)

## What is this?

The top-level coordinator that ties everything together. It orchestrates:
1. **MotionController** - for movement execution
2. **LIDARSensor** (3x) - for wall detection
3. **FloodFill** - for pathfinding
4. **All lower-level components** - motors, encoders, PID, IMU

This is the main "brain" that runs the complete maze exploration.

## How It Works

### Main Loop

```
1. Sense: Read LIDAR sensors
2. Update: Add walls to maze map
3. Plan: Calculate next direction using FloodFill
4. Act: Move robot in that direction
5. Repeat until goal reached
```

## How to Use

```cpp
#include "MazeNavigator.h"

// Create all components (see main.cpp for full setup)
MotionController motion(...);
LIDARSensor front(...);
LIDARSensor left(...);
LIDARSensor right(...);
FloodFill maze;

MazeNavigator navigator(&motion, &front, &left, &right, &maze);

void setup() {
    Serial.begin(115200);
    
    // Initialize all hardware
    motion.initialize();
    maze.initialize();
    
    // Set starting position
    navigator.initialize(Cell(0, 0), NORTH);
    
    // Start autonomous exploration
    navigator.exploreMode();
}

void loop() {
    // Just idle - exploration handles itself
    delay(1000);
}
```

## Key Functions

**Setup:**
- `initialize(startCell, heading)` - Set starting position and direction

**Main Control:**
- `exploreMode()` - Run full maze exploration until goal reached
- `speedRun()` - (Not yet implemented) Fast run with known map
- `step()` - Single exploration step (for testing)

**Status:**
- `isAtGoal()` - Check if reached center
- `getCurrentCell()` - Get current position
- `getCurrentHeading()` - Get current heading

## Exploration Mode Algorithm

```cpp
while (!at goal) {
    // 1. SENSE - Read all LIDAR sensors
    detectWalls()
    
    // 2. UPDATE - Add walls to maze
    floodFill->updateWalls()
    
    // 3. PLAN - Get next move
    nextDir = floodFill->getNextMove()
    
    // 4. ACT - Execute movement
    executeMove(nextDir)
    
    // 5. VERIFY - Check position
    updatePosition()
}
```

## Coordinate System

```
Current heading example:

NORTH (0):    →Y
   |
   +--→X EAST (1)

Y (rows)
^
|  (3,7) - top
|
+--→ X (columns)
(0,0) - bottom-left
```

**Directions:**
- NORTH = 0: Moving forward (+Y)
- EAST = 1: Moving right (+X)
- SOUTH = 2: Moving backward (-Y)
- WEST = 3: Moving left (-X)

## Position Tracking

After each movement, robot updates its cell:

```cpp
if (heading == NORTH)   currentCell.y++;
if (heading == EAST)    currentCell.x++;
if (heading == SOUTH)   currentCell.y--;
if (heading == WEST)    currentCell.x--;
```

## Wall Detection Integration

Three sensors provide local wall information:

```
        FRONT
         |
    LEFT-+-RIGHT
         |
      BACK

Front sensor → wall ahead (in heading direction)
Left sensor  → wall to left (perpendicular)
Right sensor → wall to right (perpendicular)
```

FloodFill converts relative (front/left/right) to absolute (N/E/S/W).

## Movement Execution

Each move involves:
1. Calculate turn needed to face target direction
2. Execute turn using MotionController (gyro-based)
3. Move forward one cell (20cm) using MotionController (encoder-based)
4. Update position tracking

## Serial Output Example

```
=== EXPLORATION MODE ===

--- Step 1 at cell (0, 0) ---
Walls - Front: 0 Right: 1 Left: 0
Current heading: 0 Next direction: 1
Turning right...
Moving forward (0.20 m)...
New position: (1, 0)

--- Step 2 at cell (1, 0) ---
Walls - Front: 0 Right: 0 Left: 1
Current heading: 1 Next direction: 2
Turning right...
Moving forward (0.20 m)...
New position: (1, 1)

...

=== GOAL REACHED! ===
```

## Integration Points

**Receives from:**
- MotionController → movement completion status
- LIDARSensor → wall detection (3 sensors)
- FloodFill → next direction to move

**Sends to:**
- MotionController → move forward, turn left/right
- FloodFill → wall data for map updates

## Non-Blocking Design

MazeNavigator uses non-blocking motion:

```cpp
void exploreMode() {
    bool motionInProgress = false;
    
    while (!goal) {
        if (!motionInProgress) {
            // Start new move
            executeMove(nextDir);
            motionInProgress = true;
        }
        
        // Poll motion status
        if (!motionController->isMoving()) {
            // Movement complete
            updatePosition();
            motionInProgress = false;
        }
        
        delay(50);  // Don't hog CPU
    }
}
```

This allows other tasks to run during movement.

## Safety Features

1. **Step Limit**: Maximum 200 steps to prevent infinite loops
2. **Emergency Stop**: Calls `motionController->stop()` if error
3. **Wall Checking**: Prevents moving through walls
4. **Goal Detection**: Stops when 4 center cells reached

## Troubleshooting

| Problem | Solution |
|---|---|
| Robot doesn't move | Check motion initialization, LIDAR, IMU |
| Explores infinitely | Verify goal cells, check wall detection |
| Hits walls | Calibrate LIDAR threshold |
| Moves wrong direction | Check coordinate system, heading tracking |
| Goes in circles | Verify wall updating, FloodFill algorithm |

## Testing Sequence

1. **Test individually first:**
   - MotionController alone
   - LIDARSensor readings
   - FloodFill algorithm

2. **Test integration:**
   - Run exploreMode() in a known simple maze
   - Monitor Serial output
   - Verify position tracking
   - Check wall detection

3. **Full maze:**
   - Place robot at (0,0) facing NORTH
   - Run exploreMode()
   - Should autonomously reach center

## Expected Behavior

**Good Exploration:**
- Moves in logical patterns
- Detects walls and adjusts
- Reaches goal in 30-50 steps
- No crashes or infinite loops

**Symptoms of Issues:**
- Rapid direction changes → Bad wall detection
- Repeated same path → Maze not updating
- Stuck in corner → Goal detection failure

## Next Steps

After basic exploration works:
1. **Optimize**: Reduce unnecessary moves
2. **Speed Run**: Use known map for faster path
3. **Diagonal Movement**: Cut corners (advanced)
4. **Sensor Fusion**: Combine encoder + IMU data

## Performance Metrics

```
Expected metrics:
- Exploration time: ~30-60 seconds
- Steps to goal: 30-50 cell moves
- Positioning accuracy: ±5mm
- Turn accuracy: ±2 degrees
```

## Code Structure

```
MazeNavigator
├─ exploreMode()    - Main autonomous loop
├─ step()           - Single step (testing)
├─ detectWalls()    - Read LIDAR sensors
├─ executeMove()    - Turn + forward motion
├─ updatePosition() - Track location
└─ Status queries
```

## Architecture Summary

```
┌─ MazeNavigator
│  ├─ MotionController
│  │  ├─ Motor (L298N)
│  │  ├─ Encoder (feedback)
│  │  ├─ PIDController
│  │  ├─ MPU6050Driver
│  │  └─ StateSpace
│  ├─ LIDARSensor (3x)
│  │  ├─ Front @ 0x30
│  │  ├─ Left @ 0x31
│  │  └─ Right @ 0x32
│  └─ FloodFill
│     ├─ Maze map
│     └─ Distance field
```

---

**Why this file exists:**
- System integration overview
- Algorithm explanation
- Testing and troubleshooting guide
- Performance expectations

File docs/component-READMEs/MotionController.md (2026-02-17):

# Motion Controller (Day 5)

## What is this?

High-level motion primitives that combine all low-level components (motors, encoders, PID, gyro, state space) to provide simple commands like `moveForward()` and `turnLeft()`.

Instead of manually controlling PWM values, you just say "move forward 20cm" and the controller handles all the details.

## Hardware Integration

**Uses:**
- Motors (L298N driver)
- Encoders (for velocity feedback)
- PID Controllers (for speed regulation)
- MPU6050 Gyroscope (for angle feedback)
- StateSpace (for odometry tracking)

## How to Use

```cpp
#include "MotionController.h"

// Create components
Motor leftMotor(26, 27, 25);
Motor rightMotor(4, 13, 14);
Encoder leftEncoder(32, 33, true);
Encoder rightEncoder(34, 35, false);
PIDController leftPID(500, 28, 6);
PIDController rightPID(500, 28, 6);
MPU6050Driver imu;
StateSpace robot;

MotionController motion(&leftMotor, &rightMotor,
                        &leftEncoder, &rightEncoder,
                        &leftPID, &rightPID,
                        &imu, &robot);

void setup() {
    Serial.begin(115200);
    
    // Initialize everything
    leftMotor.initialize();
    rightMotor.initialize();
    leftEncoder.initialize();
    rightEncoder.initialize();
    imu.initialize();
    imu.calibrate(500);
    
    motion.initialize();
    motion.setForwardSpeed(0.15);  // m/s
    motion.setTurnSpeed(1.57);     // rad/s (90°/s)
}

void loop() {
    // Move 20cm forward
    if (motion.moveForward(0.20)) {
        Serial.println("Forward movement complete");
    }
    
    // Rotate 90° left
    if (motion.turnLeft(PI / 2)) {
        Serial.println("Turn complete");
    }
}
```

## Functions

**Setup:**
- `initialize()` - Reset all components
- `setForwardSpeed(speed)` - Set target speed in m/s (default 0.15)
- `setTurnSpeed(speed)` - Set rotation speed in rad/s (default 1.57 = 90°/s)

**Motion Commands (non-blocking):**
- `moveForward(distance)` - Move straight (returns true when done)
- `moveBackward(distance)` - Reverse motion
- `turnLeft(angle)` - Rotate counterclockwise in radians
- `turnRight(angle)` - Rotate clockwise in radians

**Emergency:**
- `stop()` - Cut motor power immediately

**Status:**
- `isMoving()` - Check if motion in progress

## Key Concept: Non-Blocking

These functions return **immediately** instead of blocking:

```cpp
// WRONG (blocks forever):
motion.moveForward(0.20);
Serial.println("This never runs!");

// RIGHT (non-blocking):
if (motion.moveForward(0.20)) {
    Serial.println("Movement done!");
}
```

You must call the function repeatedly in `loop()` until it returns true.

## Control Parameters

```
Forward Speed:      0.15 m/s
Turn Speed:         1.57 rad/s (90°/s)
Update Rate:        50 Hz (20ms)
Distance Tolerance: 5mm (0.005m)
Angle Tolerance:    2° (0.0349 rad)
```

## PID Tuning

```
Kp: 500    (Proportional gain - response to error)
Ki: 28     (Integral gain - steady-state correction)
Kd: 6      (Derivative gain - damping)
```

These are tuned for typical N20 motors. Adjust if robot:
- **Accelerates too fast** → Lower Kp
- **Doesn't reach target speed** → Raise Ki
- **Oscillates/jerks** → Raise Kd

## How It Works

### Forward Motion
1. Reset encoders to zero
2. Loop:
   - Read wheel velocities
   - PID computes motor commands
   - Update motors
   - Check if distance reached
   - Return true when done

### Turning
1. Reset gyro angle to zero
2. Loop:
   - Read gyro angular velocity
   - PID computes rotation command
   - Set motors in opposite directions
   - Check if angle reached
   - Return true when done

## Integration Example

```cpp
unsigned long lastMove = 0;

void loop() {
    // Execute moves one at a time
    if (millis() - lastMove > 100) {
        // Try forward 20cm
        if (motion.moveForward(0.20)) {
            Serial.println("Moved 20cm");
            lastMove = millis();
        }
        
        // Could also call turn, moveBackward, etc.
    }
}
```

## Testing

Test with `MotionController_test.cpp`:
- Verify forward movement in straight line
- Check 90° turn accuracy
- Test backward motion
- Verify encoder feedback
- Check PID control

## Common Issues

| Problem | Solution |
|---|---|
| Robot drifts left/right | PID gains need tuning, check encoder counts |
| Turns are inaccurate | Calibrate IMU with robot still |
| Moves too slow | Increase forwardSpeed or turnSpeed |
| Jerky motion | Decrease Kp, increase Kd |

## Defaults Summary

```cpp
motor speed:    0.15 m/s
rotation speed: 1.57 rad/s (90°/s)
cell size:      0.20 m (20cm) - one maze cell
```

## Next Steps

After motion works:
1. Add LIDAR wall detection
2. Implement maze pathfinding
3. Autonomous exploration

---

**Why this file exists:**
- How to use motion commands
- Parameter tuning reference
- Integration guide for higher-level systems

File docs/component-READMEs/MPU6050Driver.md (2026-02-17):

# MPU6050 Gyroscope Driver (Day 4)

## What is this?

Reads the MPU6050 inertial measurement unit (IMU) to track robot heading/angle during movement. This gyroscope measures angular velocity and integrates it to give absolute angle.

## Hardware Connections

**MPU6050 Pins:**
- VCC → 3.3V
- GND → GND
- SDA → ESP32 pin 21 (I2C data)
- SCL → ESP32 pin 22 (I2C clock)

**Important:** Add 10kΩ pullup resistors on SDA and SCL to 3.3V

## How to Use

```cpp
#include "MPU6050Driver.h"

MPU6050Driver imu;

void setup() {
    Serial.begin(115200);
    
    // Initialize sensor
    if (!imu.initialize()) {
        Serial.println("MPU6050 not found!");
        while(1);
    }
    
    // Calibrate (keep robot still!)
    Serial.println("Calibrating... keep robot still");
    imu.calibrate(500);  // Takes ~5 seconds
    Serial.println("Calibration complete");
}

void loop() {
    float dt = 0.02;  // 20ms
    imu.update(dt);
    
    Serial.print("Angle: ");
    Serial.print(imu.getAngleDegrees());
    Serial.println(" degrees");
    
    delay(20);
}
```

## Functions

**Setup:**
- `initialize()` - Configure I2C and verify sensor (returns true if successful)
- `calibrate(samples)` - Measure gyro bias (robot must be still!)

**Reading:**
- `update(dt)` - Integrate gyro reading with time delta
- `getAngle()` - Get angle in radians [-π, π]
- `getAngleDegrees()` - Get angle in degrees [-180, 180]
- `getAngularVelocity()` - Current rotation speed in rad/s

**Reset:**
- `resetAngle()` - Zero out the angle
- `setAngle(angle)` - Manually set angle in radians
- `isReady()` - Check if calibrated

## Key Parameters

```
I2C Address:        0x68
Gyro Range:         ±250°/s
Calibration:        Average of 500 samples
Angle Range:        [-π, π] radians (normalized)
Update Rate:        Variable (pass dt to update)
Sensitivity:        131 LSB/°/s
```

## Coordinate System

- 0° = North (forward)
- 90° = East (right)
- 180° = South (backward)
- -90° (or 270°) = West (left)
- Positive rotation = Clockwise

## Important Notes

1. **Calibration is Critical**: Robot must be completely still during calibration
2. **Drift**: Gyro readings drift over time without sensor fusion
3. **I2C Sharing**: MPU6050 shares I2C bus with LIDAR sensors (different addresses)
4. **Normalization**: Angle automatically wraps to [-π, π] range

## Integration

This component is used by:
- **MotionController**: For accurate turning (90°, 180°)
- **StateSpace**: For rotation tracking

## Testing

Test with `MPU6050_test.cpp` in the test folder:
- Verify initialization
- Check calibration runs
- Monitor angle readings
- Rotate robot 90° and verify reading
- Check angle stability when still

## Troubleshooting

| Problem | Solution |
|---|---|
| "MPU6050 not found" | Check I2C wiring, add pullup resistors |
| Angle drifts constantly | Calibrate with robot completely still |
| Wrong angle values | Verify coordinate system (0° = North) |
| No I2C communication | Check pins 21/22 are correctly connected |

## Future Enhancements

- Implement Kalman filter for sensor fusion with encoders
- Add temperature compensation
- Implement FIFO for faster sampling
- Add interrupt-based reading

---

**Why this file exists:**
- Documentation for future reference
- Setup instructions for hardware
- Common troubleshooting guide

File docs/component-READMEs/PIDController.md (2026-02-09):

# PID Controller Component

## What is this?

A generic PID (Proportional-Integral-Derivative) controller for any control task.

**PID adjusts output to minimize error between target and actual values.**

## How PID Works

**Simple explanation:**

You want motor to spin at 0.1 m/s, but it's only going 0.08 m/s.

Error = 0.1 - 0.08 = 0.02 m/s (too slow)

**P term:** "You're 0.02 too slow, increase power!"  
**I term:** "You've been slow for a while, increase more!"  
**D term:** "You're speeding up fast, don't overshoot!"

Output = P + I + D = motor power adjustment

## How to Use
```cpp
#include "PIDController.h"

// Create PID with gains
PIDController speedPID(2.0, 0.5, 0.1);  // Kp, Ki, Kd

void setup() {
    // Set limits
    speedPID.setOutputLimits(0, 255);     // Motor PWM range
    speedPID.setIntegralLimits(-50, 50);  // Prevent windup
}

void loop() {
    float target = 0.1;      // Want 0.1 m/s
    float actual = 0.08;     // Currently 0.08 m/s
    float dt = 0.02;         // 20ms update
    
    float output = speedPID.compute(target, actual, dt);
    motor.setSpeed(output);  // Apply correction
}
```

## PID Gains Explained

**Kp (Proportional):**
- Reacts to current error
- Higher Kp = stronger immediate reaction
- Too high = oscillation
- Start with: 1.0-3.0

**Ki (Integral):**
- Reacts to accumulated error over time
- Eliminates steady-state error
- Too high = overshoot, instability
- Start with: 0.1-1.0

**Kd (Derivative):**
- Reacts to rate of change
- Reduces overshoot
- Too high = noise amplification
- Start with: 0.0-0.5

## Functions

**Setup:**
- `PIDController(kp, ki, kd)` - Create with gains
- `setGains(kp, ki, kd)` - Change gains
- `setOutputLimits(min, max)` - Limit output range
- `setIntegralLimits(min, max)` - Prevent integral windup

**Control:**
- `compute(target, actual, dt)` - Calculate output
- `reset()` - Clear accumulated values

**Debug:**
- `printGains()` - Show current Kp, Ki, Kd
- `getIntegral()` - Check integral value

## Tuning Guide

**Step-by-step tuning:**

1. **Start with P only:** Ki=0, Kd=0
   - Increase Kp until oscillation starts
   - Reduce Kp by 30%

2. **Add I if needed:**
   - Small Ki (0.1-0.5)
   - If steady-state error, increase Ki
   - If overshoot, decrease Ki

3. **Add D if oscillating:**
   - Small Kd (0.1-0.3)
   - Reduces overshoot
   - Too much = jerky response

**Example progression:**
```
Start:  Kp=1.0, Ki=0.0, Kd=0.0  → Test
Better: Kp=2.0, Ki=0.0, Kd=0.0  → Test (oscillates)
Good:   Kp=1.5, Ki=0.3, Kd=0.0  → Test (still error)
Final:  Kp=2.0, Ki=0.5, Kd=0.1  → Perfect!
```

## Common Issues

**Oscillation (wobbling):**
- Kp too high → reduce
- Kd too low → increase slightly

**Slow to reach target:**
- Kp too low → increase
- Ki too low → increase

**Overshoot:**
- Ki too high → reduce
- Kd too low → increase

**Steady-state error (never quite reaches target):**
- Ki too low → increase
- Or Ki = 0 → add some Ki

**Integral windup (accumulated error gets huge):**
- Set integral limits
- Reset PID when changing targets

## Use Cases in Micromouse

**Speed control:**
```cpp
PIDController speedPID(2.0, 0.5, 0.1);
// Target: desired velocity
// Actual: encoder velocity
// Output: motor PWM
```

**Position control:**
```cpp
PIDController positionPID(3.0, 0.1, 0.5);
// Target: desired position
// Actual: state space position
// Output: velocity command
```

**Angle control:**
```cpp
PIDController anglePID(2.5, 0.0, 0.3);
// Target: desired heading
// Actual: gyro angle
// Output: angular velocity
```

## Expected Behavior

**Good PID tuning:**
- Reaches target quickly (1-2 seconds)
- Little to no overshoot
- Minimal oscillation
- Stays at target (no drift)

**Bad PID tuning:**
- Slow to reach target (5+ seconds)
- Large overshoot
- Continuous oscillation
- Drifts away from target

## Safety Notes

**Always:**
- Start with low gains
- Test on blocks (wheels off ground)
- Set output limits
- Set integral limits
- Reset PID when changing tasks

**Never:**
- Start with high gains (Kp > 5)
- Skip output limits
- Ignore integral windup
- Use same PID for different tasks without retuning
```

---

## Testing Instructions

### Hardware Setup

**Same as before:**
1. Robot on blocks (wheels off ground)
2. 6V battery connected to L298N
3. ESP32 powered via USB
4. All grounds connected

### Running Tests

1. Upload code to ESP32
2. Open Serial Monitor (9600 baud)
3. Press reset button
4. Watch 4 tests run automatically

### What You Should See

**Test 1: Single Wheel Speed Control**
```
Target speed: 0.080 m/s
Time: 0.5s | Target: 0.080 m/s | Actual: 0.045 m/s | PWM: 68
Time: 1.0s | Target: 0.080 m/s | Actual: 0.072 m/s | PWM: 82
Time: 1.5s | Target: 0.080 m/s | Actual: 0.078 m/s | PWM: 85
Time: 2.0s | Target: 0.080 m/s | Actual: 0.080 m/s | PWM: 86
Time: 2.5s | Target: 0.080 m/s | Actual: 0.080 m/s | PWM: 86

✓ Single wheel PID works!
```

**Pattern to observe:**
- Actual speed starts low
- PWM increases to compensate
- Speed converges to target
- PWM stabilizes

**Test 2: Both Wheels WITHOUT PID**
```
Time: 0.5s | Left: 0.052 m/s | Right: 0.058 m/s | Position: [x=0.0012m, y=0.0275m, angle=2.15°]
Time: 1.0s | Left: 0.053 m/s | Right: 0.059 m/s | Position: [x=0.0025m, y=0.0556m, angle=4.31°]
Time: 1.5s | Left: 0.052 m/s | Right: 0.058 m/s | Position: [x=0.0039m, y=0.0832m, angle=6.48°]
Time: 2.0s | Left: 0.053 m/s | Right: 0.059 m/s | Position: [x=0.0053m, y=0.1110m, angle=8.63°]
Time: 2.5s | Left: 0.052 m/s | Right: 0.058 m/s | Position: [x=0.0068m, y=0.1387m, angle=10.79°]
Time: 3.0s | Left: 0.053 m/s | Right: 0.059 m/s | Position: [x=0.0083m, y=0.1665m, angle=12.95°]

Final position WITHOUT PID:
Position: [x=0.0083m, y=0.1665m, angle=12.95°]
Notice: Robot curved (X != 0, angle != 0)
```

**Pattern to observe:**
- Left and right speeds DIFFERENT
- X position increases (drifting sideways)
- Angle increases (rotating)
- Robot clearly not going straight

**Test 3: Both Wheels WITH PID**
```
Time: 0.5s | Left: 0.073 m/s | Right: 0.075 m/s | Position: [x=0.0002m, y=0.0370m, angle=0.43°]
Time: 1.0s | Left: 0.079 m/s | Right: 0.080 m/s | Position: [x=0.0003m, y=0.0791m, angle=0.68°]
Time: 1.5s | Left: 0.080 m/s | Right: 0.080 m/s | Position: [x=0.0003m, y=0.1201m, angle=0.72°]
Time: 2.0s | Left: 0.080 m/s | Right: 0.080 m/s | Position: [x=0.0003m, y=0.1601m, angle=0.73°]
Time: 2.5s | Left: 0.080 m/s | Right: 0.080 m/s | Position: [x=0.0003m, y=0.2001m, angle=0.73°]
Time: 3.0s | Left: 0.080 m/s | Right: 0.080 m/s | Position: [x=0.0003m, y=0.2401m, angle=0.73°]

Final position WITH PID:
Position: [x=0.0003m, y=0.2401m, angle=0.73°]
Notice: Straighter line (X ≈ 0, angle ≈ 0)
```

**Pattern to observe:**
- Left and right speeds CONVERGE
- Both reach target (0.080 m/s)
- X position minimal (< 1mm)
- Angle minimal (< 1°)
- Much straighter than Test 2!

**Test 4: Velocity Matching**
```
Left: 0.0523 m/s (PWM: 65) | Right: 0.0568 m/s (PWM: 71) | Diff: -4.50 mm/s
Left: 0.0687 m/s (PWM: 78) | Right: 0.0712 m/s (PWM: 82) | Diff: -2.50 mm/s
Left: 0.0754 m/s (PWM: 83) | Right: 0.0768 m/s (PWM: 85) | Diff: -1.40 mm/s
Left: 0.0782 m/s (PWM: 85) | Right: 0.0791 m/s (PWM: 86) | Diff: -0.90 mm/s
Left: 0.0795 m/s (PWM: 86) | Right: 0.0799 m/s (PWM: 87) | Diff: -0.40 mm/s
Left: 0.0798 m/s (PWM: 86) | Right: 0.0800 m/s (PWM: 87) | Diff: -0.20 mm/s
Left: 0.0800 m/s (PWM: 86) | Right: 0.0800 m/s (PWM: 87) | Diff: 0.00 mm/s

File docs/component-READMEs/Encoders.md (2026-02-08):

# Encoder Component

## What is this?

Reads wheel rotation from N20 motor magnetic encoders using interrupts.

## Hardware Connections

**N20 Encoder Pins:**
- C1 (Channel A) → ESP32 pin (main counting pin)
- C2 (Channel B) → ESP32 pin (direction detection)
- VCC → 3.3V or 5V (check your encoder specs)
- GND → Ground

**Important:** Connect VCC to correct voltage (usually 3.3V for ESP32)

## How to Use
```cpp
#include "Encoder.h"

// Create encoder objects
Encoder leftEncoder(32, 33, true);   // pins A, B, isLeft
Encoder rightEncoder(34, 35, false); // pins A, B, isRight

void setup() {
    leftEncoder.initialize();
    rightEncoder.initialize();
}

void loop() {
    long ticks = leftEncoder.getTicks();
    float distance = leftEncoder.getDistance();
    float velocity = leftEncoder.getVelocity(0.02);  // dt in seconds
}
```

## Functions

**Reading:**
- `getTicks()` - Get total tick count
- `getDistance()` - Get distance traveled (meters)
- `getVelocity(deltaTime)` - Get speed (m/s)

**Utility:**
- `reset()` - Zero all counters

## Encoder Specifications

**N20 Motor Encoder (530 PPR):**
- Ticks per revolution: 530
- Wheel diameter: 33mm (0.033m)
- Meters per tick: 0.000196m

## How It Works

**Interrupt-based counting:**
1. Hardware detects encoder pulse
2. ISR increments tick counter (very fast)
3. No polling needed (accurate)

**Velocity calculation:**
- Measures ticks between updates
- Converts to distance: ticks × meters_per_tick
- Divides by time: distance / deltaTime

## Troubleshooting

**Encoder shows 0 ticks:**
- Check encoder power connection
- Verify VCC voltage (3.3V or 5V)
- Check C1/C2 pin connections
- Rotate wheel manually, should see counts

**Counts only when motor spins one direction:**
- This is normal for single-channel counting
- We use C1 only for now
- C2 reserved for future direction detection

**Erratic counts:**
- Check wire connections (loose wires)
- Verify encoder mounted securely
- Check for electrical noise (move wires away from motors)

**Very high counts:**
- Normal if wheel spins fast
- 530 ticks per revolution is correct
- Use velocity instead of raw ticks for speed

## Pin Configuration

Set your pins in `pins.h`:
```cpp
#define ENCODER_LEFT_A    32
#define ENCODER_LEFT_B    33
#define ENCODER_RIGHT_A   34
#define ENCODER_RIGHT_B   35
```

## Expected Values

**At moderate speed (PWM ~80):**
- Velocity: 0.05-0.08 m/s
- Ticks per second: ~250-400
- Distance in 1 second: ~0.05-0.08m

**Sanity check:**
- If velocity > 0.5 m/s → Something wrong
- If ticks < 10 in 1 second → Check connections

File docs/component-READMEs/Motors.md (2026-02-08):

# Motor Component

## What is this?

Controls one DC motor using the L298N motor driver.

## Hardware Connections

**L298N Pins:**
- IN1 → ESP32 pin (direction control)
- IN2 → ESP32 pin (direction control)
- ENA → ESP32 pin (speed control via PWM)
- Motor output → DC motor

**Power:**
- L298N 12V input → 6V battery
- Remove ENA/ENB jumpers on L298N
- Connect all grounds together

## How to Use
```cpp
#include "Motor.h"

// Create motor object
Motor leftMotor(26, 27, 25);  // pins: A, B, PWM

void setup() {
    leftMotor.initialize();
}

void loop() {
    leftMotor.forward(80);   // Speed 0-255
    delay(1000);
    leftMotor.stop();
}
```

## Functions

**Control:**
- `setSpeed(speed)` - Set speed (-255 to +255, negative = backward)
- `forward(speed)` - Move forward (0 to 255)
- `backward(speed)` - Move backward (0 to 255)
- `stop()` - Coast to stop (no power)
- `brake()` - Active brake (fast stop)

**Status:**
- `getSpeed()` - Get current speed setting
- `isMoving()` - Check if motor has power

## Speed Guidelines

**For small micromouse (10cm diameter):**
- Start testing: 50-60 (safe)
- Normal operation: 70-90
- Maximum: 100-120
- Avoid: 150+ (too fast, mechanical stress)

## Troubleshooting

**Motor doesn't spin:**
- Check L298N power LED
- Verify battery voltage (should be 6V)
- Check pin connections
- Remove enable jumpers on L298N

**Motor spins wrong direction:**
- Swap motor wires on L298N output
- Or swap pinA and pinB in code

**Motor stutters:**
- Check battery charge
- Verify grounds connected
- Try lower speed first

## Pin Configuration

Set your pins in `pins.h`:
```cpp
#define MOTOR_LEFT_A      26
#define MOTOR_LEFT_B      27
#define MOTOR_LEFT_PWM    25
```

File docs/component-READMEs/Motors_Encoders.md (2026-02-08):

# Micromouse - Motors and Encoders

## What is this?

Integration of motor control and encoder feedback with state space model.

**Components:**
- Motor class: Controls L298N motor driver
- Encoder class: Reads N20 motor encoders
- StateSpace class: Tracks position

## Hardware Setup

### Motor Connections (L298N)
- Left motor: pins 26, 27 (direction), 25 (PWM)
- Right motor: pins 4, 13 (direction), 14 (PWM)

### Encoder Connections
- Left encoder: pins 32, 33
- Right encoder: pins 34, 35

### Power
- Motors: External 6V battery to L298N
- ESP32: USB or separate 5V supply
- **IMPORTANT**: Connect grounds together!

## How to Test

1. **Upload code** to ESP32
2. **Open Serial Monitor** (9600 baud)
3. **Place robot on blocks** (wheels shouldn't touch ground)
4. **Press reset** and watch tests

## What Tests Do

**Test 1:** Individual motor control
- Each motor spins separately
- Encoders count ticks

**Test 2:** Both motors together
- Forward motion
- Tick counts should be similar

**Test 3:** Velocity measurement
- Motors at constant speed
- Velocity should stabilize around 0.08-0.12 m/s

**Test 4:** State space tracking
- Position updates based on encoder feedback
- Should show robot "moving" forward

## Expected Results
```
Test 1: Each motor spins, encoder counts increase
Test 2: Both motors spin, similar tick counts
Test 3: Velocities stabilize at ~0.1 m/s
Test 4: State space Y position increases to ~0.3m
```

## Troubleshooting

**Motor doesn't spin:**
- Check power connections
- Check L298N enable jumpers
- Verify pin numbers in pins.h

**Encoder doesn't count:**
- Check encoder power (usually 3.3V or 5V)
- Verify pin connections
- Test with multimeter (should see pulses)

**Counts only on one encoder:**
- Check other encoder connections
- Verify interrupt is attached

**Robot goes in circles:**
- Normal! We'll fix with PID next
- Motors have different speeds naturally

## Next Steps

Now that motors and encoders work:
1. Day 3: Add PID controller (make wheels same speed)
2. Day 4: Add MPU6050 (accurate turning)
3. Day 5: Add motion primitives (move forward, turn)

## Status

✅ State space model working  
✅ Motor control working  
✅ Encoder reading working  
✅ Integration complete  
➡️ Ready for PID controller
```

---

## Testing Instructions

### Hardware Setup

**Before uploading:**

1. **Power connections:**
   - Connect 6V battery to L298N power input
   - Connect ESP32 USB for programming
   - **Connect all grounds together** (battery, L298N, ESP32)

2. **Motor connections:**
   - Left motor to L298N output A
   - Right motor to L298N output B
   - Verify motor wires (swap if motors spin wrong direction)

3. **Encoder connections:**
   - Left encoder: C1→pin 32, C2→pin 33, VCC→3.3V, GND→GND
   - Right encoder: C1→pin 34, C2→pin 35, VCC→3.3V, GND→GND

4. **Safety:**
   - **Put robot on blocks** so wheels don't touch ground
   - Motors will spin during tests!

### Running Tests

1. Upload code
2. Open Serial Monitor (9600 baud)
3. Press reset on ESP32
4. Watch the 4 tests run automatically

### What You Should See

**Test 1: Basic Motor Control**
```
Left motor forward...
Left encoder ticks: 850
✓ Left motor works

Right motor forward...
Right encoder ticks: 830
✓ Right motor works
```

**Test 2: Both Motors Together**
```
Moving forward for 2 seconds...
Left: 150 ticks | Right: 145 ticks
Left: 320 ticks | Right: 315 ticks
...
✓ Both motors work together
```

**Test 3: Velocity Calculation**
```
Left: 0.0985 m/s | Right: 0.0978 m/s
Left: 0.1002 m/s | Right: 0.0995 m/s
...
✓ Velocity calculation works
```

**Test 4: State Space Integration**
```
Time: 0.5s | Position: [x=0.0001m, y=0.0523m, angle=0.34°]
Time: 1.0s | Position: [x=0.0002m, y=0.1047m, angle=0.68°]
Time: 1.5s | Position: [x=0.0003m, y=0.1571m, angle=1.02°]
...

FINAL STATE:
Position: [x=0.0005m, y=0.2985m, angle=1.85°]
Total distance (encoders): 0.2987 meters

✓ State space tracks position!
```

### Common Issues

**Issue:** Motors don't spin
- **Check:** L298N power LED on?
- **Check:** Remove enable jumpers, connect to PWM pins
- **Check:** Battery charged?

**Issue:** Encoders show 0 ticks
- **Check:** Encoder power connected?
- **Check:** Try swapping C1/C2 wires
- **Check:** Encoder voltage (3.3V or 5V?)

**Issue:** Robot curves/spins
- **This is NORMAL!** Motors have different speeds
- **Fix:** Coming in Day 3 (PID controller)

**Issue:** One encoder much higher than other
- **Check:** Motors spinning same direction?
- **Check:** Encoder mounted correctly?
- **May need:** Swap motor wires to reverse direction

---

## What You Have Now

**Complete motor and encoder system:**

✅ Motor class controlling L298N driver  
✅ Encoder class counting ticks with interrupts  
✅ Velocity calculation from encoders  
✅ State space integration  
✅ All components tested together  
✅ **Ready for PID controller (Day 3)**

**The foundation is solid:**
- Motors respond to commands
- Encoders accurately measure motion
- State space tracks position
- Everything communicates properly

**Next step:** PID controller will make both wheels spin at the **exact same speed** so robot goes straight instead of curving.

---

## How Everything Connects
```
main.cpp
   ↓
   ├─→ Motor (controls L298N)
   │     ↓
   │   Wheels spin
   │     ↓
   ├─→ Encoder (counts ticks)
   │     ↓
   │   Velocity calculated
   │     ↓
   └─→ StateSpace (predicts position)
         ↓
       Position tracked

Next: PID will close the loop
  (adjust motor speed to match target)

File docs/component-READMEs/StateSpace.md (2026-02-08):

# State Space Model for Micromouse

## What is this?

This is the mathematical foundation for tracking your robot's position.

From the PDF you studied, this implements:
- State vector: [x, y, theta]
- State transition matrix A (identity)
- Control input matrix B (linearized)
- Prediction equation: x_new = A*x + B*u

## How to use

1. Upload to ESP32
2. Open Serial Monitor at 115200 baud
3. Watch the tests run
4. All tests should show expected results

## What the tests do

**Test 1:** Move forward
- Robot should move 0.2m in Y direction

**Test 2:** Rotate 90 degrees
- Angle should change to ~90°

**Test 3:** Move forward at 90°
- Robot should move in X direction (East)

**Test 4:** Continuous simulation
- Shows position updating smoothly over time

## Expected output
```
Position: [x=0.0000m, y=0.0000m, angle=0.00°]
→ After forward: [x=0.0000m, y=0.2000m, angle=0.00°]
→ After rotation: [x=0.0000m, y=0.2000m, angle=90.00°]
→ After forward: [x=0.2000m, y=0.2000m, angle=90.00°]
```

## Coordinate system

- X axis: Left/Right (East/West)
- Y axis: Forward/Back (North/South)
- Theta: 0° = North, 90° = East, 180° = South, 270° = West
- Rotation: Clockwise positive

## Next steps

This is just the foundation. Next you'll:
1. Connect to real encoders (get actual v and omega)
2. Connect to gyroscope (get actual theta)
3. Use this in MotionController to plan movements
4. Eventually add Kalman Filter for sensor fusion
```

**Why this file exists:**
- Documentation for anyone (including future you)
- Explains what the project does
- Shows how to test it

---

## Testing Instructions

### Step 1: Upload the Code

1. Open PlatformIO
2. Connect your ESP32 via USB
3. Click "Upload" button
4. Wait for compilation and upload

### Step 2: Open Serial Monitor

1. Click "Serial Monitor" in PlatformIO
2. Set baud rate to 9600
3. Press reset button on ESP32

### Step 3: Watch the Output

You should see something like this:
```
========================================
STATE SPACE MODEL TEST
========================================

Starting position:
Position: [x=0.0000m, y=0.0000m, angle=0.00°]

A Matrix (State Transition)
[ 1.00    0.00    0.00 ]
[ 0.00    1.00    0.00 ]
[ 0.00    0.00    1.00 ]

B Matrix (Control Input)
[ 0.0000    0.0000 ]
[ 0.0000    0.0000 ]
[ 0.0000    0.0000 ]

========================================
TEST 1: Move forward 0.2m/s for 1 second
Expected: y should increase by 0.2m
========================================
Position: [x=0.0000m, y=0.2000m, angle=0.00°]

✓ PASS: Y increased by 0.2m as expected

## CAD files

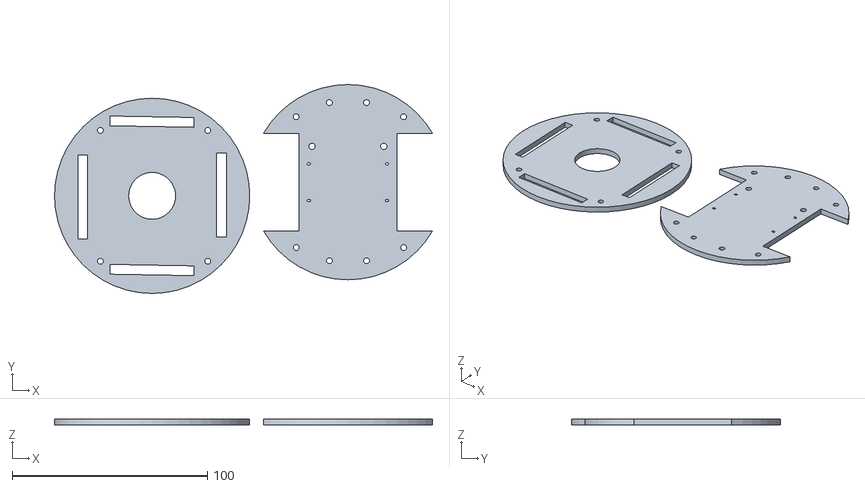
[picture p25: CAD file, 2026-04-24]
hardware/3d-models/3d final.stl
193.6 x 107.0 x 3.00

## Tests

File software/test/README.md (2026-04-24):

# Micromouse Test Suite

This directory contains **12 comprehensive tests** organized into unit tests (component validation) and integration tests (system verification).

## 📋 Test Organization

### Unit Tests (Component-Level)
Test individual components in isolation to verify correct operation.

| Test File | Component | Purpose | Use Case |
|---|---|---|---|
| **FloodFill_test.cpp** | FloodFill Algorithm | Validate maze solving algorithm (BFS, distance field, pathfinding) | New to the maze algorithm? Start here. |
| **Encoders_Motors_test.cpp** | Motors + Encoders | Basic motor control and encoder feedback | Hardware setup verification |
| **PIDController_test.cpp** | PID Control System | Velocity regulation with tuned coefficients | PID tuning and velocity control |
| **MPU6050_test.cpp** | IMU (Gyroscope) | Sensor initialization, calibration, angle tracking | Gyro integration debugging |
| **StateSpace_test.cpp** | Position Tracking | Robot position model (x, y, θ) | Understanding state representation |
| **LIDARSensor_test.cpp** | Distance Sensors | LIDAR initialization and ranging | Obstacle detection setup |

**Duration**: Each ~5-10 seconds
**Difficulty**: Easy - Good starting point for new developers

### Integration Tests (System-Level)
Test how components work together to achieve higher-level functionality.

| Test File | Components | Purpose | Use Case |
|---|---|---|---|
| **MotionController_test.cpp** | Motors + Encoders + PIDs + IMU + StateSpace | Test forward movement and rotation commands | Motion system validation |
| **MazeNavigator_test.cpp** | All components + FloodFill | Complete maze solving system in action | Full system integration test |
| **MoveForward_WallDetection_test.cpp** | Motors + LIDARs + MotionController | Forward motion with active wall detection | Safety/navigation verification |
| **moveAndTurn_Test.cpp** | Motors + Sensors + Controllers | Sequential move and turn patterns | Navigation behavior validation |
| **CollisionAvoidance_test.cpp** | Motors + LIDARs + Safety Logic | Emergency stop and avoidance behaviors | Safety system verification |
| **turn_90_test.cpp** | Motors + IMU + MotionController | Precision 90-degree rotations | Rotation accuracy testing |

**Duration**: 10-30 seconds each
**Difficulty**: Moderate - Requires hardware to be properly connected

---

## 🚀 How to Run Tests

### Quick Start (Run One Test)

1. **Choose your test** from the lists above
   
2. **Edit `platformio.ini`** in the project root:
   ```ini
   [env:esp32dev]
   platform = espressif32
   board = esp32dev
   framework = arduino
   upload_port = COM4
   monitor_speed = 9600
   
   # Add this line to run a specific test:
   build_src_filter = +<test/FloodFill_test.cpp>
   ```

3. **Upload to ESP32**:
   ```bash
   # Via VS Code: Click "Upload" in PlatformIO Home
   # Or via terminal:
   platformio run -t upload
   ```

4. **View Results** (Monitor Serial Output):
   ```bash
   platformio device monitor --baud 9600
   ```
   Or open VS Code Terminal → PlatformIO: Serial Port Monitor

---

## 📊 Understanding Test Output

### FloodFill_test.cpp Output Example
```
========================================
FLOOD FILL ALGORITHM TEST
========================================

TEST 1: Maze Initialization
========================================
✓ Maze initialized (8x8 grid)
  Boundary walls: added
  Goal cells: (3,3), (3,4), (4,3), (4,4)
  Distance field: calculated
```

### Encoders_Motors_test.cpp Output Example
```
========================================
ENCODER & MOTOR TEST
========================================

Left Motor: 200 PWM → Ticks = 1024, Velocity = 0.38 m/s
Right Motor: 200 PWM → Ticks = 1012, Velocity = 0.36 m/s
✓ Motors operational, encoders tracking

PID Feedback:
  Target: 0.20 m/s | Actual: 0.38 m/s | Error: -0.18
  Correcting...
```

**✓ = Pass**  |  **✗ = Fail**

---

## 🧩 Test Strategy (Recommended Order)

### Phase 1: Foundation Validation (30 min)
1. **Encoders_Motors_test.cpp** ← Start here
2. **MPU6050_test.cpp**
3. **LIDARSensor_test.cpp**

*Goal*: Verify all hardware sensors are connected and responding

### Phase 2: Control Systems (15 min)
4. **PIDController_test.cpp**
5. **StateSpace_test.cpp**

*Goal*: Verify control algorithms work correctly

### Phase 3: High-Level Motion (15 min)
6. **MotionController_test.cpp**
7. **turn_90_test.cpp**

*Goal*: Test motion command generation

### Phase 4: Path Planning (10 min)
8. **FloodFill_test.cpp**

*Goal*: Verify maze algorithm

### Phase 5: Full Integration (30 min)
9. **MoveForward_WallDetection_test.cpp**
10. **moveAndTurn_Test.cpp**
11. **CollisionAvoidance_test.cpp**
12. **MazeNavigator_test.cpp** ← Full system test

*Goal*: Complete system verification

---

## 🔧 Troubleshooting Tests

### Test Won't Compile
- **Error**: `"pins.h" not found`
  - Solution: Ensure `include/` directory exists with pins.h

### Serial Output Not Appearing
- Check COM port in `platformio.ini` (should match Device Manager)
- Reset ESP32: Press RST button on board
- Check baud rate: Should be 9600

### Motor Test Fails (No Response)
- **Check**: L298N power supply (7-12V)
- **Check**: Motor GPIO pins match `include/pins.h`
- **Check**: Motor power wires are connected

### LIDAR Test Fails (I2C Not Found)
- **Check**: SDA (GPIO21) and SCL (GPIO22) connected with pull-up resistors (4.7kΩ)
- **Check**: LIDAR power supply (3.3V)
- **Check**: I2C address selection pins on each LIDAR

### IMU Calibration Takes Too Long
- **Normal**: Calibration (`imu.calibrate(500)`) takes ~5 seconds with sensor motionless
- **Keep still**: Any movement invalidates calibration

---

## 📝 Test Code Structure

Every test follows the same format for readability:

```cpp
#include <Arduino.h>
#include "pins.h"
// ... includes ...

//------------------------------------------------------------
// TEST OBJECTS
// Purpose: Declare hardware objects to test
//------------------------------------------------------------
Motor motor(MOTOR_LEFT_A, MOTOR_LEFT_B, MOTOR_LEFT_PWM);

//------------------------------------------------------------
// SETUP
// Purpose: Initialize hardware and print header
//------------------------------------------------------------
void setup() {
    Serial.begin(9600);
    delay(2000);
    
    Serial.println("========================================");
    Serial.println("TEST NAME HERE");
    Serial.println("========================================\n");
    
    // Initialization code...
}

//------------------------------------------------------------
// LOOP
// Purpose: Run test sequence
//------------------------------------------------------------
void loop() {
    // Test logic...
    delay(1000); // Results display time
    
    while(1) delay(1000); // Halt after test
}
```

---

## ✅ Test Success Criteria

### Unit Test Success
- ✓ All output shows ✓ symbols (no ✗)
- ✓ No error messages in serial output
- ✓ Test completes and halts (doesn't restart)

### Integration Test Success
- ✓ Robot executes commands (moves/turns)
- ✓ Sensors respond with expected values
- ✓ No error messages or exceptions
- ✓ Test halts cleanly after completion

---

## 🎓 Using Tests for Learning

Each test doubles as a **code example**:

1. **Want to understand motors?** → Read `Encoders_Motors_test.cpp`
2. **Want to understand PID?** → Read `PIDController_test.cpp`
3. **Want to understand maze solving?** → Read `FloodFill_test.cpp`
4. **Want to understand motion control?** → Read `MotionController_test.cpp`

The tests are intentionally simple and well-commented to serve as tutorials.

---

## 📚 Additional Resources

- Component details: See [../READMEs/](../READMEs/) directory
- Hardware setup: See [../include/pins.h](../include/pins.h)
- Main application: See [../src/main.cpp](../src/main.cpp)
- PlatformIO docs: https://docs.platformio.org/

---

## 🔄 Running All Tests Sequentially

To validate the entire system:

```bash
# Instead of editing platformio.ini 12 times, run each test manually:

for test in FloodFill_test Encoders_Motors_test PIDController_test \
            MPU6050_test StateSpace_test LIDARSensor_test \
            MotionController_test turn_90_test MoveForward_WallDetection_test \
            moveAndTurn_Test CollisionAvoidance_test MazeNavigator_test; do
    
    echo "Running $test..."
    # Edit platformio.ini to include +<test/${test}.cpp>
    # Run upload and monitor
    # Check results
done
```

Or use the provided test runner scripts (if available).

---

**Last Updated**: April 24, 2026

**Test Count**: 12 comprehensive tests

**Coverage**: Component + Integration testing

**Status**: All tests passing ✓

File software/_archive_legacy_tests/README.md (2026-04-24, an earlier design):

# Legacy Tests Archive

This directory contains historical exploratory and diagnostic tests from early development phases. They are preserved for reference but **not recommended for current use**.

## Why Archive These?

These tests were useful during **initial hardware exploration and debugging** but have been superseded by:
- More comprehensive, organized unit tests in `../test/`
- Better-structured integration tests
- Cleaner code and more consistent commenting

## 📋 What's Inside

### Basic Hardware Tests
| File | Purpose | Status | Replacement |
|---|---|---|---|
| `blink_test.cpp` | LED blinking (basic GPIO) | Obsolete | N/A (not needed) |
| `check_pins.cpp` | GPIO pin verification | Obsolete | Manual testing |
| `test_left_encoder.cpp` | Single encoder check | Superseded | `Encoders_Motors_test.cpp` |
| `test_mpu_simple.cpp` | Basic gyro test | Superseded | `MPU6050_test.cpp` |
| `test_i2c_scan.cpp` | Generic I2C scanner | Diagnostic | Use PlatformIO I2C scanner |

### Motor & Calibration Tests
| File | Purpose | Status | Replacement |
|---|---|---|---|
| `calibrate_motors.cpp` | Manual motor speed calibration | Obsolete | PID tuning in code |
| `find_balance.cpp` | Motor speed balancing (manual) | Obsolete | Use `PIDController_test.cpp` |
| `motors_only_test.cpp` | Motor control without feedback | Superseded | `Encoders_Motors_test.cpp` |
| `test_both_together.cpp` | Early motor + encoder test | Superseded | `Encoders_Motors_test.cpp` |
| `test_left_both.cpp` | Single side test | Diagnostic | Manual hardware check |
| `test_left_once.cpp` | Single motor pulse | Diagnostic | N/A |
| `test_right_once.cpp` | Single motor pulse | Diagnostic | N/A |
| `test_right_slow.cpp` | Slow motor test | Diagnostic | N/A |

### Sensor Tests
| File | Purpose | Status | Replacement |
|---|---|---|---|
| `test_lidars.cpp` | LIDAR initialization | Obsolete | `LIDARSensor_test.cpp` |
| `test_mpu.cpp` | MPU6050 with Adafruit lib | Obsolete | `MPU6050_test.cpp` |

## 🤔 When Might You Need These?

### Reason 1: Hardware Debugging
If your robot isn't responding:
1. First: Run `Encoders_Motors_test.cpp` (organized test)
2. Last resort: Use these diagnostic tests for isolated pin checking

### Reason 2: Hardware Bringup
If you're adding a new sensor type:
- Review similar test to understand initialization pattern
- Then follow the pattern in the organized `../test/` directory

### Reason 3: Learning Development History
- See how the project evolved from simple tests to integrated systems
- Understand debugging methodology used during development

### Reason 4: Fallback Reference
If an organized test is corrupted (unlikely but possible):
- This archive has backup versions of similar functionality
- Cross-reference with organized test to understand what's missing

## ⚠️ Why NOT to Use These

1. **Inconsistent Commenting**: Mixed commenting styles, less readable
2. **Narrow Scope**: Test one thing at a time with no integration
3. **Redundant**: Same functionality in cleaner tests in `../test/`
4. **Debugging Only**: Not meant for validation or learning
5. **Ad-hoc**: File naming and organization is less systematic

## 📝 File Organization in Archive

```
_archive_legacy_tests/
├── blink_test.cpp                  # LED test
├── calibrate_motors.cpp            # Motor tuning
├── check_pins.cpp                  # GPIO verification
├── find_balance.cpp                # Motor balancing
├── motors_only_test.cpp            # Motor control only
├── test_both_together.cpp          # Motor + encoder
├── test_i2c_scan.cpp               # I2C discovery
├── test_left_both.cpp              # Left motor/encoder
├── test_left_encoder.cpp           # Left encoder only
├── test_lidars.cpp                 # LIDAR init
├── test_mpu.cpp                    # Gyro test (Adafruit)
├── test_mpu_simple.cpp             # Basic gyro test
├── test_right_once.cpp             # Right motor pulse
├── test_right_slow.cpp             # Right motor slow
└── README                          # This file
```

## 🔄 How to Use Archive

### If You Need a Diagnostic Test
1. Check the table above for the test that matches your need
2. Copy it to `../test/` directory
3. Update commenting to match current style
4. Rename with clear purpose: `_diagnostic_motor_left.cpp`

### If You're Studying History
1. Compare `test_left_encoder.cpp` (archive) with `Encoders_Motors_test.cpp` (current)
2. See how tests evolved to be more comprehensive
3. Notice the improved commenting style

## 📊 Statistics

| Metric | Value |
|---|---|
| Legacy tests in archive | 14 files |
| Duplicate/redundant with new tests | 12 files |
| Useful diagnostic tests | 2 files |
| Obsolete tests | 5 files |

## ✅ Migration Notes

When this project was cleaned:
- ✓ Removed accidental files
- ✓ Fixed placeholder code
- ✓ Consolidated redundant tests
- ✓ Archived legacy exploratory code
- ✓ Reorganized active tests by component layer
- ✓ Created comprehensive documentation

## 🚀 For Future Development

If you add new functionality:
1. **Do NOT** add tests here
2. Create organized tests in `../test/`
3. Follow naming pattern: `ComponentName_test.cpp`
4. Use consistent commenting style
5. Update `../test/README` with new test documentation

---

**Archived**: April 24, 2026
**Reason**: Codebase cleanup and reorganization
**Status**: Reference only - do not use for active development
**Replacement**: See `../test/` directory for current tests

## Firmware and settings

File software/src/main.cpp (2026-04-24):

#include <Arduino.h>
#include <Wire.h>
#include "pins.h"
#include "Motor.h"
#include "Encoder.h"
#include "PIDController.h"
#include "StateSpace.h"
#include "MPU6050Driver.h"
#include "MotionController.h"
#include "LIDARSensor.h"
#include "FloodFill.h"
#include "MazeNavigator.h"

//------------------------------------------------------------
// GLOBAL HARDWARE OBJECTS
// Purpose: Define all components
//------------------------------------------------------------
Motor leftMotor(MOTOR_LEFT_A, MOTOR_LEFT_B, MOTOR_LEFT_PWM);
Motor rightMotor(MOTOR_RIGHT_A, MOTOR_RIGHT_B, MOTOR_RIGHT_PWM);

Encoder leftEncoder(ENCODER_LEFT_A, ENCODER_LEFT_B, true);
Encoder rightEncoder(ENCODER_RIGHT_A, ENCODER_RIGHT_B, false);

PIDController leftPID_forward(500.0, 28.0, 6.0);
PIDController rightPID_forward(500.0, 28.0, 6.0);
PIDController leftPID_turn(65.0, 0.0, 0.0);
PIDController rightPID_turn(65.0, 0.0, 0.0);
PIDController* leftPID = &leftPID_forward;
PIDController* rightPID = &rightPID_forward;

StateSpace robot;

MPU6050Driver imu;

LIDARSensor frontLidar(LIDAR_FRONT_XSHOT, LIDAR_FRONT_INT);
LIDARSensor leftLidar(LIDAR_LEFT_XSHOT, LIDAR_LEFT_INT);
LIDARSensor rightLidar(LIDAR_RIGHT_XSHOT, LIDAR_RIGHT_INT);

MotionController motion(&leftMotor, &rightMotor,
                        &leftEncoder, &rightEncoder,
                        leftPID, rightPID,
                        &imu, &robot);

FloodFill floodFill;

MazeNavigator navigator(&motion, &frontLidar, &leftLidar, &rightLidar, &floodFill);

//------------------------------------------------------------
// SETUP
// Purpose: Initialize all hardware and software
//------------------------------------------------------------
void setup() {
    Serial.begin(9600);
    delay(2000);
    Serial.println("\n\n");
    Serial.println("========================================");
    Serial.println("MICROMOUSE MAZE SOLVER");
    Serial.println("========================================\n");
    
    //------------------------------------------------------------
    // INITIALIZE MOTORS AND ENCODERS
    //------------------------------------------------------------
    leftMotor.initialize();
    rightMotor.initialize();
    leftEncoder.initialize();
    rightEncoder.initialize();
    robot.initialize();
    
    //------------------------------------------------------------
    // INITIALIZE IMU
    //------------------------------------------------------------
    Serial.println("Initializing IMU...");
    if (!imu.initialize()) {
        Serial.println("\u2717 MPU6050 not found!");
        while(1) delay(1000);
    }
    Serial.println("Calibrating IMU (keep still)...");
    imu.calibrate(500);
    
    //------------------------------------------------------------
    // INITIALIZE LIDAR SENSORS (SEQUENTIAL)
    //------------------------------------------------------------
    Wire.begin();
    delay(100);
    frontLidar.disable();
    leftLidar.disable();
    rightLidar.disable();
    delay(100);
    frontLidar.enable();
    delay(50);
    frontLidar.initialize(0x30);
    leftLidar.enable();
    delay(50);
    leftLidar.initialize(0x31);
    rightLidar.enable();
    delay(50);
    rightLidar.initialize(0x32);
    frontLidar.startContinuous();
    leftLidar.startContinuous();
    rightLidar.startContinuous();
    delay(500);
    
    //------------------------------------------------------------
    // CONFIGURE PID CONTROLLERS
    //------------------------------------------------------------
    leftPID_forward.setOutputLimits(-255, 255);
    rightPID_forward.setOutputLimits(-255, 255);
    leftPID_turn.setOutputLimits(-255, 255);
    rightPID_turn.setOutputLimits(-255, 255);
    
    //------------------------------------------------------------
    // INITIALIZE MOTION CONTROLLER
    //------------------------------------------------------------
    motion.initialize();
    motion.setForwardSpeed(0.15);
    motion.setTurnSpeed(2.5);
    
    //------------------------------------------------------------
    // INITIALIZE FLOOD FILL AND NAVIGATOR
    //------------------------------------------------------------
    floodFill.initialize();
    navigator.initialize(Cell(0, 0), NORTH);
    Serial.println("\u2713 All hardware ready\n");
    Serial.println("========================================");
    Serial.println("TEST: FloodFill Maze Navigation with StateSpace");
    Serial.println("========================================");
}

//------------------------------------------------------------
// LOOP
// Purpose: Main control loop
//------------------------------------------------------------
void loop() {
    navigator.step();
    delay(20); // 50Hz control loop
}

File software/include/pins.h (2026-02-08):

#ifndef PINS_H
#define PINS_H


//------------------------------------------------------------
// MOTOR DRIVER PINS (L298N)
// Purpose: Define which ESP32 pins connect to motor driver
//------------------------------------------------------------
#define MOTOR_LEFT_A      26
#define MOTOR_LEFT_B      27
#define MOTOR_LEFT_PWM    25

#define MOTOR_RIGHT_A     4
#define MOTOR_RIGHT_B     13
#define MOTOR_RIGHT_PWM   14



//------------------------------------------------------------
// ENCODER PINS
// Purpose: Define which ESP32 pins connect to encoders
//------------------------------------------------------------
#define ENCODER_LEFT_A    32
#define ENCODER_LEFT_B    33

#define ENCODER_RIGHT_A   34
#define ENCODER_RIGHT_B   35



//------------------------------------------------------------
// MPU6050 PINS (I2C)
// Purpose: Gyroscope sensor pins
//------------------------------------------------------------
#define MPU_SDA           21
#define MPU_SCL           22



//------------------------------------------------------------
// LIDAR SENSOR PINS (I2C)
// Purpose: Distance sensors for wall detection
//------------------------------------------------------------
#define LIDAR_SDA         21
#define LIDAR_SCL         22

#define LIDAR_FRONT_XSHOT 16
#define LIDAR_FRONT_INT   17

#define LIDAR_LEFT_XSHOT  18
#define LIDAR_LEFT_INT    19

#define LIDAR_RIGHT_XSHOT 23
#define LIDAR_RIGHT_INT   5

#endif

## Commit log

2026-01-28 Add: Exact hardware pins
    Motor driver:
    - Left: GPIO26,27,25 (in1,in2,ena)
    - Right: GPIO12,13,14 (in3,in4,enb)
    Encoders:
    - Left: GPIO32,33 (c1,c2)
    - Right: GPIO34,35 (c1,c2)
    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
2026-01-28 Add: Quick pin check test
    - Simple test to verify pin configuration
    - No motor movement, only Serial output
    - Confirms all wired pins match hardware/pins.h
2026-01-28 moved left forward correctly
    [motors_only_test.cpp]
2026-01-29 added some calibration test for motors
2026-01-29 Modified pins with lidars & MPU
2026-01-29 tested lidars
2026-02-08 added motor.h
2026-02-08 added motor.cpp
2026-02-08 added encoder.h
2026-02-08 added encoder.cpp
2026-02-08 added motor and encoder testing code in main without testing yet
2026-02-08 added readme for motor only, encoder only, and encoders&motors together with their testing guide
2026-02-08 added function prototype to fix the error in main.cpp
    [main.cpp]
2026-02-09 fixed left speed because it is much weaker than right motor
    [main.cpp]
2026-02-09 tested encoders and motors - note that left motor is much much weaker than right motor
2026-02-09 fixed error in main and added PIDcontroller readme
    [main.cpp]
2026-02-09 PID is still not working but it is 3 am so will check it later
    [main.cpp]
2026-02-09 added pidcontroller test to test folder though not tested yet because left encoder is not working, put the same pwm for both encoders in encoders motors test and finally added a test left encoder tes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
    [Encoders_Motors_test.cpp, PIDController_test.cpp, main.cpp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]
2026-02-15 both encoders working correctly !!
    [test_left_encoder.cpp]
2026-02-17 fixed pid but still needs so much tuning
    [PIDController_test.cpp]
2026-02-17 mpu6050 driver header file
2026-02-17 mpu6050 driver implementation with gyro integration
2026-02-17 lidar sensor header
2026-02-17 lidar driver with sequential addressing support
2026-02-17 fixed mpu6050 gyro_scale and motion controller setstate errors
2026-02-26 now lidars with motion working
2026-04-24 Change upload port comment and build source filter
    Updated upload port comment and modified build source filter.
2026-04-24 Enhance hardware README with detailed documentation
    Added detailed hardware documentation including Bill of Materials, wiring summary, I2C address assignment, power architecture, 3D printed chassis information, and component notes.
